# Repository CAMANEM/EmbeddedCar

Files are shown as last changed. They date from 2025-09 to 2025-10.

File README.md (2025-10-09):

# EmbeddedCar Project

This project contains the development environment for an embedded car system, organized in a clean and modular structure.

## Table of Contents

- [System Architecture](#system-architecture)
- [Key Features](#key-features)
- [API Documentation](#api-documentation)
- [Project Structure](#project-structure)
- [Prerequisites Installation](#prerequisites-installation)
    - [Yocto Prerequisites](#yocto-prerequisites)
    - [Web Development Prerequisites](#web-development-prerequisites)
- [Project Instructions](#project-instructions)
    - [Embedded Development (Yocto)](#embedded-development-yocto)
    - [Web Development](#web-development)
- [Setup Instructions for New Developers](#setup-instructions-for-new-developers)
    - [1. Prerequisites Installation](#1-prerequisites-installation)
    - [2. Configure Git with Your GitLab Credentials](#2-configure-git-with-your-gitlab-credentials)
    - [3. Authentication Setup](#3-authentication-setup)
    - [4. Clone and Setup Repository](#4-clone-and-setup-repository)
    - [5. Configure VS Code for GitLab](#5-configure-vs-code-for-gitlab)
    - [6. Development Workflow](#6-development-workflow)
    - [7. Important Configuration Notes](#7-important-configuration-notes)
    - [8. Troubleshooting](#8-troubleshooting)
- [Version Information](#version-information)
- [Contributing](#contributing)
- [License](#license)

##  System Architecture

### Overall Architecture Diagram

```
┌─────────────────────────────────────────────────────────────────┐
│                        EmbeddedCar System                       │
└─────────────────────────────────────────────────────────────────┘
                                  │
                    ┌─────────────┼─────────────┐
                    │             │             │
         ┌──────────▼──────────┐  │  ┌─────────▼─────────┐
         │   Web Interface     │  │  │  Embedded System  │
         │   (Frontend)        │  │  │  (Raspberry Pi)   │
         └─────────────────────┘  │  └───────────────────┘
                    │             │             │
    ┌───────────────┼─────────────┼─────────────┼──────────────┐
    │               │             │             │              │
┌───▼───┐    ┌──────▼──────┐   ┌──▼──┐   ┌─────▼─────┐   ┌────▼────┐
│Angular│    │   Node.js   │   │HTTP │   │  Yocto    │   │ Hardware│
│Client │    │   Backend   │   │API  │   │  Linux    │   │ Control │
└───────┘    └─────────────┘   └─────┘   └───────────┘   └─────────┘
```

### Component Architecture

####  **Frontend-Angular 20.2.1**
```
┌─────────────────────────────────────────────────────────────┐
│                    Angular Frontend                         │
├─────────────────────────────────────────────────────────────┤
│  ┌─────────────┐  ┌──────────────┐  ┌─────────────────────┐ │
│  │ Dashboard   │  │   Services   │  │     Components      │ │
│  │ Component   │  │              │  │                     │ │
│  │             │  │ ┌──────────┐ │  │ ┌─────────────────┐ │ │
│  │ • Manual    │  │ │Movement  │ │  │ │ • D-pad Control │ │ │
│  │   Control   │  │ │Service   │ │  │ │ • Speed Slider  │ │ │
│  │ • Sensors   │  │ └──────────┘ │  │ │ • Video Stream  │ │ │
│  │ • Cameras   │  │ ┌──────────┐ │  │ │ • Status Panel  │ │ │
│  │ • FPV       │  │ │Auth      │ │  │ └─────────────────┘ │ │
│  │ • Config    │  │ │Service   │ │  │                     │ │
│  └─────────────┘  │ └──────────┘ │  └─────────────────────┘ │
└─────────────────────────────────────────────────────────────┘
```

#### **Backend- Node.js**
```
┌─────────────────────────────────────────────────────────────┐
│                    Node.js Backend API                      │
├─────────────────────────────────────────────────────────────┤
│  ┌─────────────┐  ┌──────────────┐  ┌─────────────────────┐ │
│  │   Routes    │  │ Middleware   │  │    Controllers      │ │
│  │             │  │              │  │                     │ │
│  │ • /api/move │  │ • CORS       │  │ • Movement Control  │ │
│  │ • /api/stop │  │ • Auth       │  │ • Camera Streaming  │ │
│  │ • /api/     │  │ • Logging    │  │ • Sensor Reading    │ │
│  │   camera    │  │ • Error      │  │ • GPIO Management   │ │
│  │ • /api/     │  │   Handling   │  │                     │ │
│  │   sensors   │  │              │  │                     │ │
│  └─────────────┘  └──────────────┘  └─────────────────────┘ │
└─────────────────────────────────────────────────────────────┘
```

####  **Embedded- Yocto Linux + Hardware**
```
┌─────────────────────────────────────────────────────────────┐
│                 Raspberry Pi Hardware                       │
├─────────────────────────────────────────────────────────────┤
│  ┌─────────────┐  ┌──────────────┐  ┌─────────────────────┐ │
│  │Yocto Linux  │  │   Drivers    │  │      Hardware       │ │
│  │             │  │              │  │                     │ │
│  │ • Custom    │  │ • GPIO       │  │ • DC Motors         │ │
│  │   Build     │  │ • Camera     │  │ • Servo Motors      │ │
│  │ • Minimal   │  │ • (gstreamer)│  │ • Camera Module     │ │
│  │   Kernel    │  │              │  │ • Power Management  │ │
│  │ • Network   │  │              │  │                     │ │
│  │   Stack     │  │              │  │                     │ │
│  └─────────────┘  └──────────────┘  └─────────────────────┘ │
└─────────────────────────────────────────────────────────────┘
```
### Communication 

The system follows a structured communication pattern that ensures reliable, real-time control of the integrated vehicle:

#### **1. User Interaction **
The user interacts with the system using multiple input methods:
- **Web Interface**: Pressing buttons, adjusting sliders, or using touch controls
- **Keyboard Input**: Using the arrow keys and spacebar for direct control

#### **2. Frontend Processing**
The Angular frontend processes user input and manages the interface:
- **Event Handling**: Captures user interactions (clicks, keystrokes, touch events)
- **State Handling**: Maintains the current vehicle state, speed settings, and connection status
- **Input Validation**: Ensures commands are within valid ranges (speed 0-100%, valid directions)
- **User Feedback**: Updates visual indicators and status displays immediately

#### **3. HTTP Communication **
The frontend communicates with the backend using RESTful HTTP requests:
- **Request Format**: Converts user actions into structured JSON payloads
- **API Calls**: Sends POST/GET requests to specific endpoints (/api/move/forward, /api/stop, etc.)
- **Error Handling**: Handles network timeouts, connection failures, and invalid responses
- **Retry Logic**: Implements automatic retries for failed requests

#### **4. Backend API **
The Node.js backend processes incoming requests and manages communication with the hardware:
- **Request Parsing**: Validates and parses incoming JSON data
- **Authentication**: Verifies user permissions and session validity
- **Command Translation**: Converts high-level commands into hardware-specific instructions
- **Concurrent Management**: Securely handles multiple simultaneous requests

#### **5. Hardware Control Layer (GPIO)**
The backend interacts directly with the Raspberry Pi hardware:
- **GPIO Management**: Controls digital pins for motor direction and speed
- **PWM Control**: Generates pulse-width modulation signals for precise speed control
- **Sensor Reading**: Monitors hardware sensors for status information
- **Security Checks**: Implements hardware-level security mechanisms

#### **6. Physical Response Layer**
Hardware responds to control signals:
- **Motor Control**: DC motors respond to direction and speed commands
- **Servo Control**: Steering servos adjust to specific angles
- **Sensor Feedback**: Hardware sensors provide real-time status information
- **Power Management**: Monitors battery levels and power consumption

#### **7. Feedback Loop**
The system maintains real-time feedback through a continuous monitoring cycle:
- **Status Monitoring**: The hardware continuously reports the current status
- **API Response**: The backend sends JSON responses with the current status
- **Frontend Updates**: Angular updates the interface with real-time information
- **Visual Feedback**: The user sees immediate feedback through status indicators and video streaming

#### **Communication Protocols Used**
- **HTTP/HTTPS**: Primary communication protocol between the frontend and backend
- **WebSocket**: For real-time video streaming and continuous status updates
- **GPIO Protocol**: Direct hardware communication on the Raspberry Pi

##  Key Features

### **Complete Web Interface**
- **Manual Control**: Interactive D-pad for directional movement
- **Keyboard Control**: Arrow keys functional from any section
- **Speed Control**: Slider for velocity adjustment (0-100%)

###  **Video System**
- **Real-time Streaming**: GStreamer + MJPEG fallback
- **FPV View**: Game-like control with overlays
- **Screenshot Capture**: Automatic PNG image download
- **Flexible Configuration**: Configurable IP and port

### **Embedded System**
- **Yocto Linux**: Optimized custom build
- **Raspberry Pi**: Native hardware support
- **REST API**: Node.js backend for communication
- **GPIO Control**: Direct motor and sensor management

### **Monitoring**
- **Vehicle Status**: Real-time visual indicators
- **Network Connection**: Connectivity monitoring
- **Sensors**: Dedicated section for telemetry

## API Documentation

### Base URL
```
http://raspberry-pi-ip:3000/api
```

### Authentication Endpoints

#### POST `/auth/login`
**Description**: Authenticate user and obtain access token
```json
Request Body:
{
  "username": "admin",
  "password": "password"
}

Response:
{
  "status": "success",
  "token": "jwt-token-here",
  "user": {
    "username": "admin",
    "role": "admin"
  }
}
```

### Movement Control Endpoints

#### POST `/move/forward`
**Description**: Move vehicle forward
```json
Request Body:
{
  "speed": 75,
  "duration": 1000
}

Response:
{
  "status": "Moving forward.",
  "speed": 75,
  "direction": "forward"
}
```

#### POST `/move/backward`
**Description**: Move vehicle backward
```json
Request Body:
{
  "speed": 50,
  "duration": 1000
}

Response:
{
  "status": "Moving backward.",
  "speed": 50,
  "direction": "backward"
}
```

#### POST `/move/left`
**Description**: Turn vehicle left
```json
Request Body:
{
  "angle": 45,
  "speed": 60
}

Response:
{
  "status": "Turning left.",
  "angle": 45,
  "speed": 60
}
```

#### POST `/move/right`
**Description**: Turn vehicle right
```json
Request Body:
{
  "angle": 45,
  "speed": 60
}

Response:
{
  "status": "Turning right.",
  "angle": 45,
  "speed": 60
}
```

#### POST `/move/stop`
**Description**: Stop all vehicle movement
```json
Response:
{
  "status": "Stopped.",
  "timestamp": "2025-10-07T20:30:00Z"
}
```

### Camera Endpoints

#### GET `/camera/gstreamer-stream`
**Description**: Get GStreamer video stream
```
Query Parameters:
- ip: Raspberry Pi IP address
- port: Stream port (default: 8080)

Response: Binary video stream
Content-Type: multipart/x-mixed-replace
```

#### GET `/camera/mjpeg-stream`
**Description**: Get MJPEG video stream (fallback)
```
Query Parameters:
- ip: Raspberry Pi IP address  
- port: Stream port (default: 8080)

Response: Binary MJPEG stream
Content-Type: multipart/x-mixed-replace
```

### Sensor Endpoints

#### GET `/sensors/status`
**Description**: Get all sensor readings
```json
Response:
{
  "temperature": 25.6,
  "humidity": 60.2,
  "distance": 150.5,
  "battery": 85,
  "timestamp": "2025-10-07T20:30:00Z"
}
```

### Error Responses

All endpoints may return these error responses:
```json
400 Bad Request:
{
  "error": "Invalid parameters",
  "message": "Speed must be between 0 and 100"
}

401 Unauthorized:
{
  "error": "Authentication required",
  "message": "Please provide valid credentials"
}

500 Internal Server Error:
{
  "error": "Hardware communication failed",
  "message": "Unable to control motors"
}
```

## Project Structure

```
EmbeddedCar/
├── .gitignore          # Git ignore rules for both embedded and web development
├── README.md           # This file - project overview
└── Embedded/           # Yocto/Embedded system development
    ├── bitbake/        # BitBake build system
    ├── meta/           # Core OpenEmbedded metadata
    ├── meta-poky/      # Poky distribution metadata
    ├── meta-yocto-bsp/ # BSP layers for supported hardware
    ├── scripts/        # Build and utility scripts
    ├── oe-init-build-env # Environment setup script
    └── ...             # Other Yocto components
```

## Prerequisites Installation

### Yocto Prerequisites

Make sure you have the following packages installed on your system (example for Ubuntu/Debian):

```bash
sudo apt-get install gawk wget git diffstat unzip texinfo gcc-multilib
build-essential chrpath socat cpio python3 python3-pip python3-pexpect
xz-utils debianutils iputils-ping python3-git python3-jinja2 python3-subunit
zstd liblz4-tool file locales libacl1
```
Or you can use the `yocto_setup_and_test.sh` in the main directory to automatically the basic dependencies for this Yocto project.

Refer to the [official Yocto documentation](https://docs.yoctoproject.org/current/brief-yoctoprojectqs/index.html#packages) for more details and supported operating systems.

### Web Development Prerequisites

For the web part, ensure you have:

- [Node.js](https://nodejs.org/) (recommended version: 18.x or higher)
- [npm](https://www.npmjs.com/) (comes with Node.js)

To install on Ubuntu/Debian:

```bash
sudo apt-get update
sudo apt-get install nodejs npm
```

Then, inside your web frontend directory (e.g., `WebInterface/`):

```bash
cd WebInterface/
$ npm install
$ npm install angular
$ npm install multer
$ npm install http-proxy-middleware

```

This will install all necessary dependencies for web development.

## Project Instructions

### Embedded Development (Yocto)

To set up the embedded development environment:

1. Navigate to the embedded directory:
   ```bash
   cd Embedded/
   ```

2. Source the build environment:
   ```bash
   source oe-init-build-env
   ```

3. Build the image for Raspberry Pi 4:

`bitbake rpi4-embeddedcar-image`

You can see the full deteiled instructions in the [README.Instr.md](Embedded/README.Instr.md)

### Web Development

## Setup Instructions for New Developers

This repository is hosted on both GitLab and GitHub:
- **Primary repository**: GitLab (for development)
- **Mirror repository**: GitHub (automatically synced)

**Due to the mirroring it is to make sure to commit the changes in the GitLab repository**, so follow these steps to clone the repository and configure it properly for GitLab development:

### 1. Prerequisites Installation

#### Install Git
Ensure Git is installed on your system:
```bash
git --version
```
If not installed, install it:
- **Ubuntu/Debian**: `sudo apt install git`

#### Install Visual Studio Code
Download and install VS Code from [https://code.visualstudio.com/](https://code.visualstudio.com/) or from Ubuntu Software.

### 2. Configure Git with Your GitLab Credentials

Set your GitLab username and email globally:
```bash
git config --global user.name "Your Full Name"
git config --global user.email "your.email@example.com"
```

### 3. Authentication Setup

#### Option A: SSH Key (Recommended)

1. **Generate SSH key** (if you don't have one):
```bash
ssh-keygen -t ed25519 -C "your.email@example.com"
```
Press Enter to accept defaults (saves to `~/.ssh/id_ed25519`)

2. **Add SSH key to ssh-agent**:
```bash
eval "$(ssh-agent -s)"
ssh-add ~/.ssh/id_ed25519
```

3. **Copy public key**:
```bash
cat ~/.ssh/id_ed25519.pub
```

4. **Add to GitLab**:
   - Go to GitLab.com → Avatar → **Preferences**
   - Left sidebar: **SSH Keys**
   - Paste your public key and click **Add key**

5. **Test connection**:
```bash
ssh -T git@gitlab.com
```

#### Option B: Personal Access Token

1. **Generate token in GitLab**:
   - Go to GitLab.com → Avatar → **Preferences**
   - Left sidebar: **Access Tokens**
   - Click **Add new token**
   - Set scopes: `api`, `read_repository`, `write_repository`, `read_user`, Set GitLab as default remote:
```
git config remote.pushdefault gitlab
```
   - Copy the generated token

2. **Store credentials** (Git will prompt when needed):
```bash
git config --global credential.helper store
```

### 4. Clone and Setup Repository

1. **Clone the repository**:
```bash
# Using SSH (recommended if you set up SSH key)
git clone git@gitlab.com:camanem/EmbeddedCar.git

# OR using HTTPS (if using Personal Access Token)
git clone https://gitlab.com/camanem/EmbeddedCar.git
```

2. **Navigate to project directory**:
```bash
cd EmbeddedCar
```

3. **Set up remotes properly**:
```bash
# Verify current remotes
git remote -v

# Add GitLab as primary remote (if not already set)
git remote add gitlab git@gitlab.com:camanem/EmbeddedCar.git

# Set GitLab as default push remote
git config remote.pushdefault gitlab
git config push.default current
```

4. **Switch to development branch**:
```bash
git checkout development
```

### 5. Configure VS Code for GitLab

1. **Open project in VS Code**:
```bash
code .
```

2. **Install recommended extensions**:
   - **GitLab Workflow**: `GitLab.gitlab-workflow`
   - **Git Graph**: `mhutchie.git-graph`
   - **Git Lens**: `eamodio.gitlens`

3. **Configure GitLab Workflow extension**:
   - Press `Ctrl+Shift+P` → type "GitLab: Add Account"
   - Enter GitLab instance URL: `https://gitlab.com`
   - Use your Personal Access Token if prompted

4. **Verify Source Control setup**:
   - Open Source Control panel (`Ctrl+Shift+G`)
   - Check that remote shows as GitLab
   - Make a test change and commit to verify it goes to GitLab

### 6. Development Workflow

#### Creating and Working on Branches

1. **Always branch from development**:
```bash
git checkout development
git pull gitlab development
git checkout -b your_new_branch_name
```

2. **Make changes and commit**:
```bash
# Stage changes
git add .

# Commit with descriptive message
git commit -m "feat: add new feature description"

# Push to GitLab
git push gitlab your_new_branch_name
```

3. **Create Merge Request**:
   - Go to GitLab project page
   - Create Merge Request from your branch to `development`
   - Add description and assign reviewers

#### VS Code Source Control Usage

- **Stage files**: Click `+` next to files in Source Control panel
- **Commit**: Type message and press `Ctrl+Enter`
- **Push**: Click `...` → Push (or `Ctrl+Shift+P` → "Git: Push")
- **Pull**: Click `...` → Pull (or `Ctrl+Shift+P` → "Git: Pull")

### 7. Important Configuration Notes

- **Never push directly to `main` or `master`**
- **Always create branches from `development`**
- **Commits automatically sync from GitLab to GitHub** (mirroring is configured)
- **Use GitLab for all development work**, GitHub is read-only mirror

### 8. Troubleshooting

#### If commits go to GitHub instead of GitLab:
```bash
git remote set-url origin git@gitlab.com:camanem/EmbeddedCar.git
git config remote.pushdefault origin
```

#### If authentication fails:
```bash
# For SSH
ssh -T git@gitlab.com

# For HTTPS, clear and re-enter credentials
git config --global --unset credential.helper
git config --global credential.helper store
```

#### To verify remote configuration:
```bash
git remote -v
git config --list | grep remote
```

## Version Information

- **Yocto Version**: Scarthgap (5.0.10)
- **Build System**: BitBake
- **Architecture**: Multi-platform embedded systems

## Contributing

Please make sure to:
1. Test your changes in a clean build environment
2. Update documentation when adding new features
3. Follow the existing code structure and naming conventions

## License

This project inherits the licenses from the Yocto Project:
- MIT License (see `Embedded/LICENSE.MIT`)
- GPL v2.0 (see `Embedded/LICENSE.GPL-2.0-only`)

For more information about the embedded components, see the documentation in `Embedded/documentation/`.

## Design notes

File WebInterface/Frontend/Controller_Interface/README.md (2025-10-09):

# EmbeddedCar - Controller Interface 

This is the web application for remotely controlling an integrated autonomous vehicle. This interface offers real-time control, video streaming, and monitoring via a responsive web dashboard.





## Table of Contents

- [Features](#features)
- [Technologies Used](#technologies-used)
- [Prerequisites](#prerequisites)
- [Installation](#installation)
- [Configuration](#configuration)
- [Development](#development)
- [Building](#building)
- [Project Structure](#project-structure)
- [API Integration](#api-integration)
- [Troubleshooting](#troubleshooting)

## Features

### **Vehicle Control**
- **Interactive D-pad**: Touch-friendly directional control
- **Global Keyboard Control**: Arrow keys work from any section
- **Speed Control**: Adjustable velocity slider (0-100%)
- **Real-time Status**: Live vehicle state indicators

### **Video System**
- **Live Streaming**: GStreamer and MJPEG support
- **FPV Mode**: First-person view with gaming-like controls
- **Screenshot Capture**: Save video frames as PNG files
- **Configurable Streaming**: Adjustable IP and port settings

###  **User Interface**
- **Multi-section Layout**: Manual, Sensors, Cameras, FPV, Configuration
- **Real-time Feedback**: Instant visual response to commands

### **Authentication & Security**
- **Login Component**: Dedicated login form with username/password validation
- **Session Management**: JWT token storage and automatic renewal
- **Route Protection**: AuthGuard prevents unauthorized access to dashboard
- **Secure Logout**: Complete session cleanup and redirection
- **Input Validation**: Client-side and server-side parameter validation
- **Error Handling**: User-friendly authentication error messages

## Technologies Used

- **Framework**: Angular 20.2.1
- **Language**: TypeScript
- **Styling**: CSS3 with Flexbox/Grid
- **Forms**: Angular Reactive Forms
- **HTTP Client**: Angular HttpClient for API communication
- **Routing**: Angular Router for navigation
- **Build Tool**: Angular CLI
- **Package Manager**: npm

## Prerequisites

Before running this application, ensure you have:

- **Node.js**: Version 18.x or higher
- **npm**: Version 9.x or higher (comes with Node.js)
- **Angular CLI**: Version 20.x
- **Modern Web Browser**: Chrome, Firefox, Safari, or Edge

### Installation of Prerequisites

```bash
# Install Node.js (Ubuntu/Debian)
sudo apt update
sudo apt install nodejs npm

# Install Angular CLI globally
npm install -g @angular/cli

# Verify installations
node --version
npm --version
ng version
```

##  Installation

1. **Clone the repository** (if not already done):
```bash
git clone <repository-url>
cd EmbeddedCar/WebInterface/Frontend/Controller_Interface
```

2. **Install dependencies**:
```bash
npm install
```

3. **Verify installation**:
```bash
npm list --depth=0
```

## Configuration

### Environment Configuration

Create or modify environment files for different deployment scenarios:

**src/environments/environment.ts** (Development):
```typescript
export const environment = {
  production: false,
  apiUrl: 'http://localhost:3000/api',
  raspberryPiDefaultIp: '192.168.0.117',
  streamPort: 8080,
  enableLogging: true
};
```

**src/environments/environment.prod.ts** (Production):
```typescript
export const environment = {
  production: true,
  apiUrl: 'http://your-raspberry-pi-ip:3000/api',
  raspberryPiDefaultIp: 'your-raspberry-pi-ip',
  streamPort: 8080,
  enableLogging: false
};
```

### Backend Connection

Make sure your backend API is running and accessible:
- **Development**: Backend should be running on `http://localhost:3000`
- **Production**: Update the API URL to match your Raspberry Pi's IP address

##  Development

### Development server

To start a local development server, run:

```bash
ng serve
```

Once the server is running, open your browser and navigate to `http://localhost:4200/`. The application will automatically reload whenever you modify any of the source files.

### Hot Reload Development

The development server supports hot reload, meaning:
- Changes to TypeScript files trigger automatic recompilation
- CSS changes are applied instantly without page refresh
- Template changes update the DOM automatically
- The browser automatically refreshes when needed

### Development Tools

Recommended browser extensions for development:
- **Angular DevTools**: For debugging Angular applications
- **Redux DevTools**: If using state management
- **JSON Formatter**: For API response debugging

##  Project Structure

```
src/
├── app/
│   ├── login/                    
│   │   ├── login.ts              
│   │   ├── login.html            
│   │   └── login.css             
│   ├── dashboard/               
│   │   ├── dashboard.ts          
│   │   ├── dashboard.html        
│   │   └── dashboard.css         
│   ├── services/                 
│   │   ├── auth.service.ts       
│   │   └── movement.service.ts   
│   ├── guards/                   
│   │   └── auth.guard.ts         
│   ├── models/                   
│   │   ├── user.model.ts        
│   │   └── api-response.model.ts 
│   ├── app.routes.ts             
│   ├── app.component.ts         
│   ├── app.component.html        
│   └── app.component.css         
├── assets/                       
│   ├── images/                   
│   └── icons/                   
├── environments/                 
│   ├── environment.ts            
│   └── environment.prod.ts       
└── styles.css                   
```

### Key Components

#### **Components**
- **LoginComponent**: User authentication interface with form validation
- **DashboardComponent**: Main control interface with all vehicle control sections
- **AppComponent**: Root component handling routing and global layout

#### **Services**
- **AuthService**: Handles user authentication, session management, and token storage
- **MovementService**: Manages all vehicle control API calls and responses

#### **Guards & Security**
- **AuthGuard**: Protects routes requiring authentication
- **Route Protection**: Prevents unauthorized access to dashboard

#### **Models & Interfaces**
- **User Model**: TypeScript interface for user data structure
- **API Response Models**: Interfaces for backend response handling

##  API Integration

The frontend communicates with the backend through HTTP requests:

### Service Configuration

```typescript
// movement.service.ts example
@Injectable({
  providedIn: 'root'
})
export class MovementService {
  private apiUrl = environment.apiUrl;
  
  moveForward(speed: number): Observable<any> {
    return this.http.post(`${this.apiUrl}/move/forward`, { speed });
  }
}
```

### Error Handling

The application includes robust error handling:
- Network connectivity issues
- API server unavailability
- Invalid response formats
- Authentication failures

## Code scaffolding

Angular CLI includes powerful code scaffolding tools. To generate a new component, run:

```bash
ng generate component component-name
```

For a complete list of available schematics (such as `components`, `directives`, or `pipes`), run:

```bash
ng generate --help
```

## Building

To build the project run:

```bash
ng build
```

This will compile your project and store the build artifacts in the `dist/` directory. By default, the production build optimizes your application for performance and speed.

##  Troubleshooting

### Common Issues and Solutions

#### **Issue**: Application won't start
```bash
# Clear npm cache and reinstall
npm cache clean --force
rm -rf node_modules package-lock.json
npm install
```

#### **Issue**: Cannot connect to backend API
- Verify backend server is running on correct port
- Check CORS configuration in backend
- Confirm API URL in environment files
- Check API endpoints with browser developer tools

#### **Issue**: Video streaming not working
- Verify Raspberry Pi IP address and port
- Check network connectivity to Raspberry Pi
- Ensure GStreamer is properly configured on Pi
- Try MJPEG fallback option

#### **Issue**: Keyboard controls not responding
- Check browser console for JavaScript errors
- Verify event listeners are properly attached
- Ensure no other elements are capturing key events
- Try refreshing the browser or clearing cache

#### **Issue**: Build failures
```bash
# Update Angular CLI and dependencies
npm update -g @angular/cli
npm update
ng update
```

### Browser Compatibility
- Chrome 90+
- Firefox 88+
- Safari 14+
- Edge 90+

##  Additional Resources

### Angular Documentation
- [Angular Official Documentation](https://angular.dev)
- [Angular CLI Command Reference](https://angular.dev/tools/cli)
- [TypeScript Handbook](https://www.typescriptlang.org/docs/)

### Project-Specific Resources
- [Backend API Documentation](../../../Backend/README.md)
- [Embedded System Documentation](../../../Embedded/README.md)
- [Main Project README](../../../README.md)

### Development Tools
- [Angular DevTools](https://angular.dev/tools/devtools)
- [VS Code Angular Extensions](https://marketplace.visualstudio.com/items?itemName=Angular.ng-template)

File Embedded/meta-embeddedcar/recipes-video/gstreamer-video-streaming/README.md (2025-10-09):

# 🎥 GStreamer Video Streaming - Receta Yocto

## 📋 Descripción

Esta receta Yocto integra completamente el sistema de video streaming GStreamer en tu imagen de Raspberry Pi 4, proporcionando:

- ✅ **Servicio systemd** automático al arranque
- ✅ **Script de control** bash completo
- ✅ **Aplicación C++** de control avanzado
- ✅ **Configuración** centralizada
- ✅ **Logging** y monitoreo

## 📁 Estructura de la Receta

```
meta-embeddedcar/recipes-video/gstreamer-video-streaming/
├── gstreamer-video-streaming_1.0.0.bb     # Receta principal
└── files/
    ├── gstreamer-video-streaming           # Script bash principal
    ├── gstreamer-video.conf               # Archivo de configuración
    ├── gstreamer-video-streaming.service  # Servicio systemd
    ├── gstreamer_controller.cpp           # Controlador C++
    └── CMakeLists.txt                     # Build system
```

## 🚀 Instalación en Yocto

### 1. **La receta ya está incluida en tu imagen:**

```bitbake
# En: meta-embeddedcar/recipes-core/images/rpi4-embeddedcar-image.bb
IMAGE_INSTALL += "gstreamer-video-streaming"
```

### 2. **Construir la imagen:**

```bash
cd /home/camanem/EmbeddedCar/Embedded
source oe-init-build-env rpi4
bitbake rpi4-embeddedcar-image
```

### 3. **La imagen incluirá automáticamente:**

- `/usr/bin/gstreamer-video-streaming` - Script principal
- `/usr/bin/gstreamer_controller` - Controlador C++
- `/etc/gstreamer-video.conf` - Configuración
- `/lib/systemd/system/gstreamer-video-streaming.service` - Servicio
- Todas las dependencias GStreamer necesarias

## 🔧 Uso en Raspberry Pi

### **Servicio SystemD (Automático)**

```bash
# El servicio inicia automáticamente al arrancar
systemctl status gstreamer-video-streaming

# Control manual
systemctl start gstreamer-video-streaming
systemctl stop gstreamer-video-streaming
systemctl restart gstreamer-video-streaming

# Ver logs
journalctl -u gstreamer-video-streaming -f
```

### **Script Bash**

```bash
# Control directo
gstreamer-video-streaming start
gstreamer-video-streaming stop
gstreamer-video-streaming status
gstreamer-video-streaming config

# Con variables de entorno
VIDEO_PORT=8090 gstreamer-video-streaming start
VIDEO_WIDTH=1280 VIDEO_HEIGHT=720 gstreamer-video-streaming start
```

### **Controlador C++**

```bash
# Control desde aplicación C++
gstreamer_controller start
gstreamer_controller stop
gstreamer_controller status

# Con parámetros
gstreamer_controller start --port=8090 --quality=95
gstreamer_controller start --width=1280 --height=720
```

## ⚙️ Configuración

### **Archivo: `/etc/gstreamer-video.conf`**

```bash
# Video Device
VIDEO_DEVICE="/dev/video0"

# Resolution  
VIDEO_WIDTH="640"
VIDEO_HEIGHT="480"
VIDEO_FRAMERATE="30"

# Network
VIDEO_HOST="0.0.0.0"
VIDEO_PORT="8080"

# Quality
VIDEO_QUALITY="85"

# Auto-start
AUTO_START="true"
```

### **Variables de Entorno Soportadas:**

- `VIDEO_DEVICE` - Dispositivo de video
- `VIDEO_WIDTH` / `VIDEO_HEIGHT` - Resolución
- `VIDEO_FRAMERATE` - FPS
- `VIDEO_PORT` - Puerto TCP
- `VIDEO_QUALITY` - Calidad JPEG (1-100)
- `VIDEO_HOST` - Host bind

## 📊 Dependencias Incluidas

### **Runtime (RDEPENDS):**

- `gstreamer1.0` - Core GStreamer
- `gstreamer1.0-plugins-base` - Plugins básicos
- `gstreamer1.0-plugins-good` - Plugins estables
- `gstreamer1.0-plugins-bad` - Plugins experimentales
- `v4l-utils` - Video4Linux utils
- `systemd` - Service management
- `bash` - Script execution

### **Recomendadas (RRECOMMENDS):**

- `gstreamer1.0-plugins-ugly` - Plugins adicionales
- `gstreamer1.0-libav` - Codecs FFmpeg
- `gstreamer1.0-omx` - Hardware acceleration
- `kernel-module-uvcvideo` - USB camera support

## 🔍 Debugging y Logs

### **Logs del Sistema:**

```bash
# SystemD logs
journalctl -u gstreamer-video-streaming -f

# Archivo de log directo
tail -f /var/log/gstreamer-video.log

# Estado del servicio
systemctl status gstreamer-video-streaming
```

### **Verificación Manual:**

```bash
# Verificar dispositivo de video
ls -la /dev/video*

# Verificar puerto
netstat -tlpn | grep :8080

# Test GStreamer manual
gst-launch-1.0 v4l2src device=/dev/video0 ! fakesink
```

## 🌐 Integración Web

### **Tu servidor Node.js puede consumir el stream:**

```javascript
// Endpoint ya implementado:
GET /api/camera/gstreamer-stream?ip=192.168.0.106&port=8080
```

### **Interfaz web disponible:**

```
http://localhost:3000/gstreamer_video.html
```

## 🎯 Ventajas de esta Implementación

### ✅ **Integración Completa**
- Automáticamente incluido en imagen Yocto
- Servicio systemd nativo
- Configuración centralizada

### ✅ **Producción Ready**
- Auto-start en arranque
- Logging completo
- Monitoreo systemd
- Configuración segura

### ✅ **Flexible**
- Control via systemd, bash script, o C++
- Configuración por archivo o variables
- Parámetros runtime ajustables

### ✅ **Mantenible**
- Código fuente en receta
- Versionado con imagen
- Dependencias gestionadas automáticamente

## 🔄 Proceso de Build

```bash
# 1. La receta se procesa durante bitbake
bitbake gstreamer-video-streaming

# 2. Se incluye automáticamente en la imagen
bitbake rpi4-embeddedcar-image

# 3. Al flashear e iniciar RPi4:
#    - Servicio se instala
#    - Se habilita automáticamente  
#    - Inicia en boot
#    - Stream disponible en puerto 8080
```

## ✨ **¡Completamente Automatizado!**

Con esta receta, tu Raspberry Pi 4:

1. **🚀 Arranca** con video streaming automático
2. **📡 Expone** TCP stream en puerto 8080  
3. **🔧 Permite** control completo via systemd/scripts
4. **📋 Registra** todo en logs sistemd
5. **🌐 Integra** perfectamente con tu API Node.js

**¡Tu solución de video streaming está lista para producción!** 🎬

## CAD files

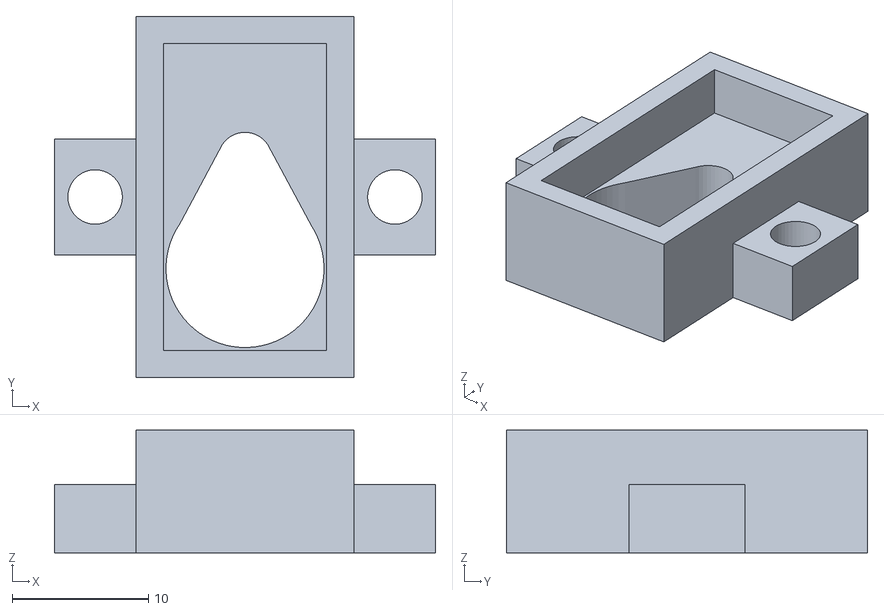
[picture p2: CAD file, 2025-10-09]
3dModels/servoHolder.stl
28.0 x 26.5 x 9.00

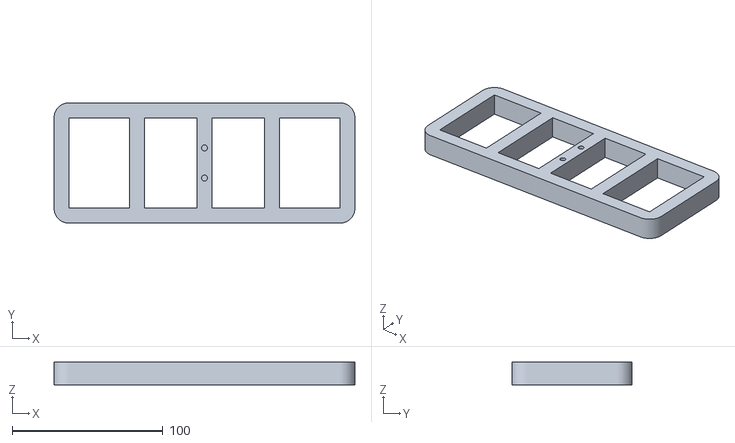
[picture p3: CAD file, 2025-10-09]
3dModels/chassis.stl
200.0 x 80.0 x 15.0

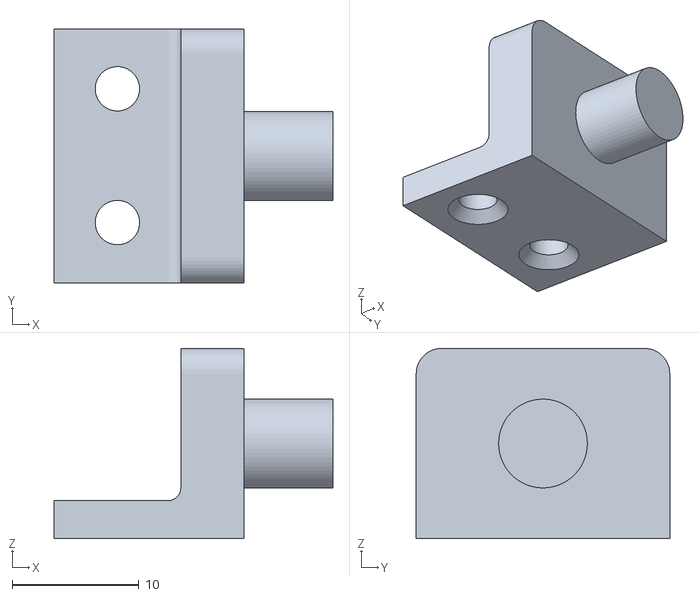
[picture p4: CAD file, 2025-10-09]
3dModels/wheelAdapter.stl
22.0 x 20.0 x 15.0

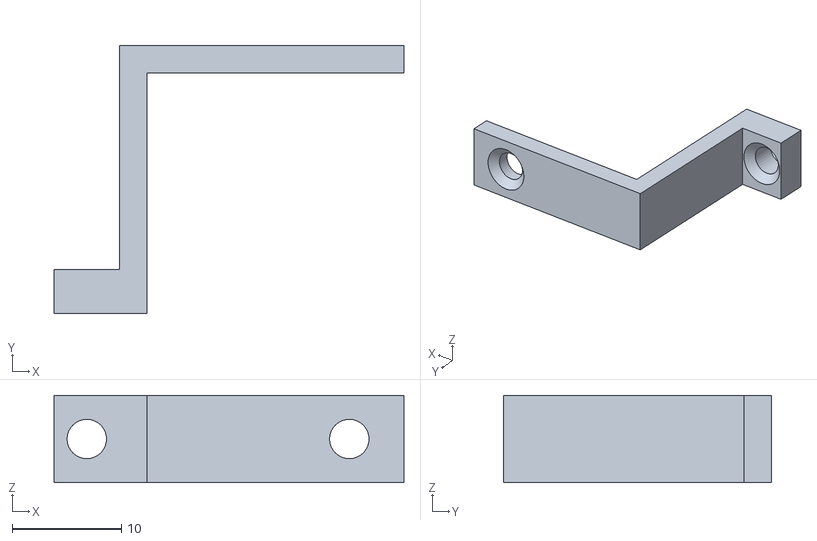
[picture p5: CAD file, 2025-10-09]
3dModels/servoHolderArm.stl
32.0 x 24.5 x 8.00

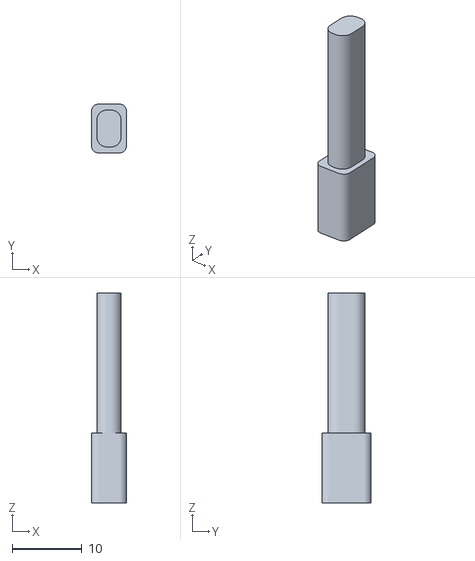
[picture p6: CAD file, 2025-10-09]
3dModels/motorToWheel.stl
5.00 x 7.00 x 30.0

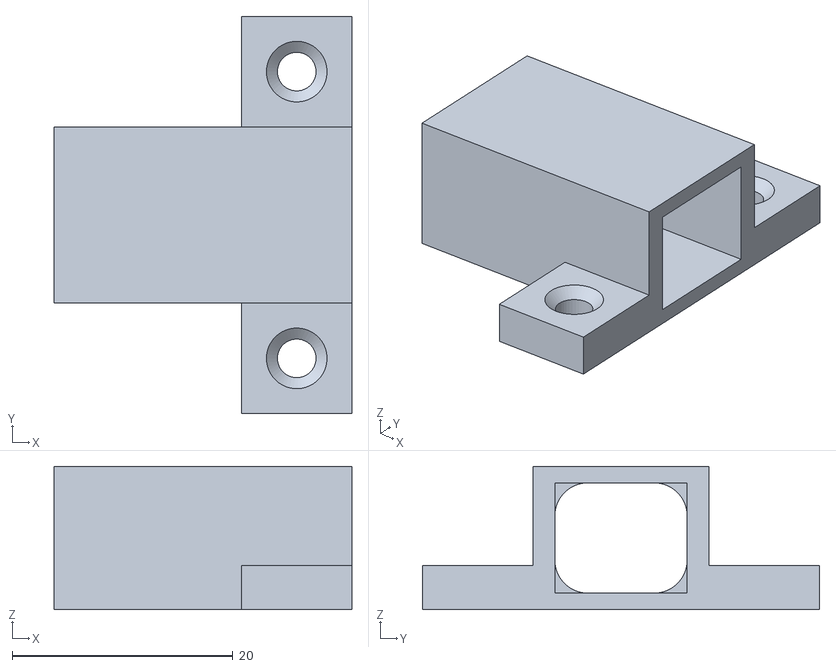
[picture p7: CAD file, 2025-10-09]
3dModels/motorBracketSmall.stl
27.0 x 36.0 x 13.0

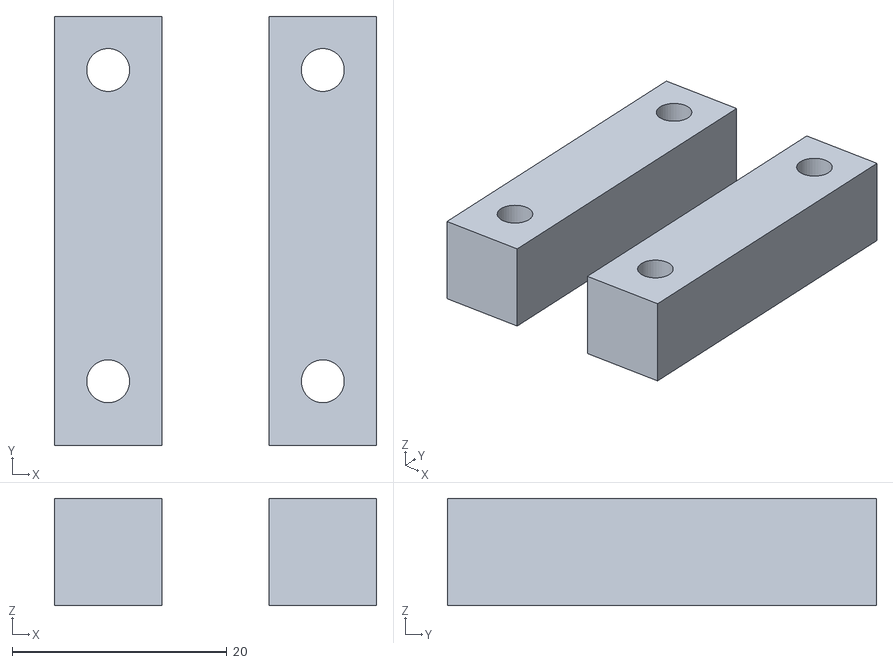
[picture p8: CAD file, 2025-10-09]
3dModels/motorSpacers.stl
30.0 x 40.0 x 10.0

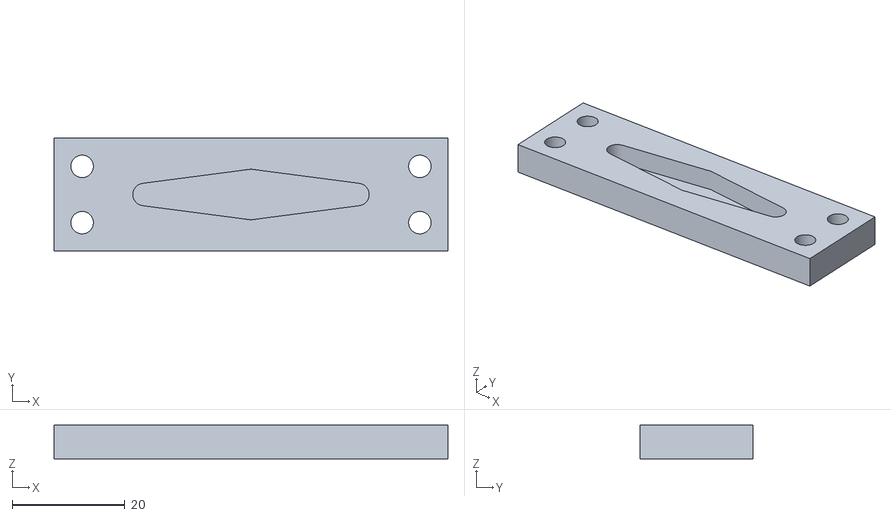
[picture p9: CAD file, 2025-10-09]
3dModels/Direction.stl
70.0 x 20.0 x 6.00

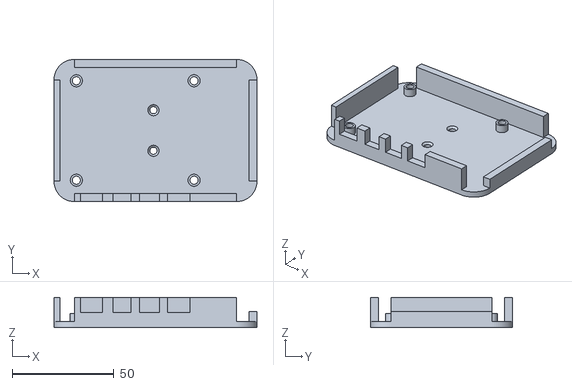
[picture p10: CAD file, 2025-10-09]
3dModels/rpi4Case.stl
100.0 x 70.0 x 15.0

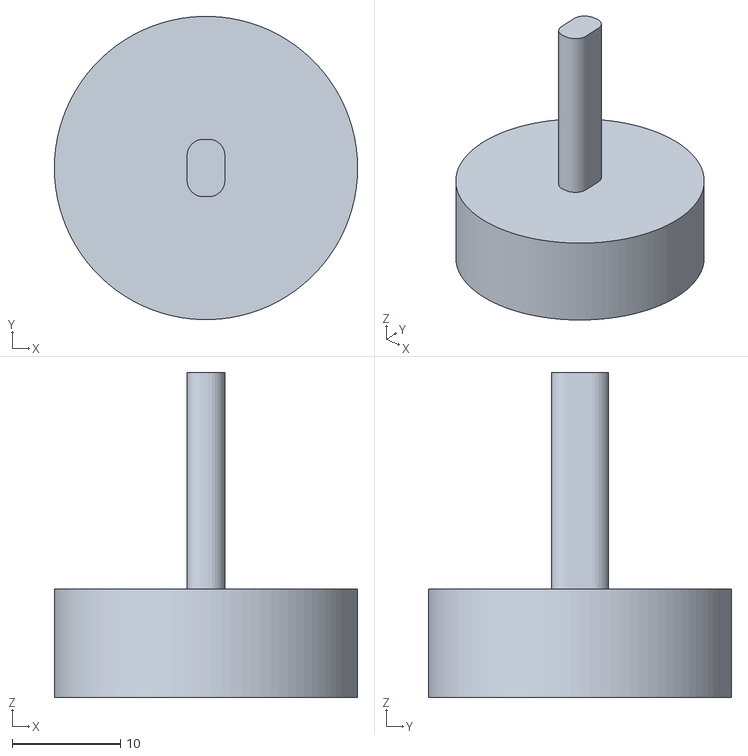
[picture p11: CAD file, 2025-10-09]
3dModels/rollAdapter.stl
28.0 x 28.0 x 30.0

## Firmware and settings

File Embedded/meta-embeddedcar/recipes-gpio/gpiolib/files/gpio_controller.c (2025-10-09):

#include "gpio_lib.h"
#include <json-c/json.h>
#include <signal.h>
#include <sys/time.h>
#include <sys/wait.h>

// GPIO Pin definitions for car control
#define LED_FORWARD_RIGHT 17
#define LED_FORWARD_LEFT 27
#define LED_BACKWARD_LEFT 6
#define LED_BACKWARD_RIGHT 5
#define PWM_MOTOR_LEFT_1 22
#define PWM_MOTOR_LEFT_2 23
#define PWM_MOTOR_RIGHT_1 26
#define PWM_MOTOR_RIGHT_2 16
#define PWM_SERVO 12


// Car control structure
typedef struct {
    char movement[16];
    int speed;
    char direction[16];
} CarCommand;

// Global variables
volatile int running = 1;
CarCommand last_command = {"stop", 0, "center"};
char server_ip[16] = "10.90.36.240";  // IP por defecto, puede ser modificada por argumento

// Signal handler for clean shutdown
void signal_handler(int sig) {
    //printf("\n Received signal %d, shutting down gracefully...\n", sig);
    running = 0;
}

// Validar formato básico de IP
int is_valid_ip_format(const char *ip) {
    int dots = 0;
    int digit_count = 0;
    
    for (int i = 0; ip[i] != '\0'; i++) {
        if (ip[i] == '.') {
            if (digit_count == 0 || digit_count > 3) return 0; // No digits before dot or too many
            dots++;
            digit_count = 0;
        } else if (ip[i] >= '0' && ip[i] <= '9') {
            digit_count++;
        } else {
            return 0; // Invalid character
        }
    }
    
    // Should have exactly 3 dots and end with digits
    return (dots == 3 && digit_count > 0 && digit_count <= 3);
}

// Parse JSON response and extract car command
int parse_car_command(const char *json_string, CarCommand *cmd) {
    json_object *root, *movement_obj, *speed_obj, *direction_obj;
    
    root = json_tokener_parse(json_string);
    if (root == NULL) {
        printf("❌ Failed to parse JSON\n");
        return -1;
    }
    
    // Extract movement
    if (json_object_object_get_ex(root, "movement", &movement_obj)) {
        const char *movement = json_object_get_string(movement_obj);
        strncpy(cmd->movement, movement, sizeof(cmd->movement) - 1);
        cmd->movement[sizeof(cmd->movement) - 1] = '\0';
    } else {
        strcpy(cmd->movement, "stop");
    }
    
    // Extract speed
    if (json_object_object_get_ex(root, "speed", &speed_obj)) {
        cmd->speed = json_object_get_int(speed_obj);
    } else {
        cmd->speed = 0;
    }
    
    // Extract direction
    if (json_object_object_get_ex(root, "direction", &direction_obj)) {
        const char *direction = json_object_get_string(direction_obj);
        strncpy(cmd->direction, direction, sizeof(cmd->direction) - 1);
        cmd->direction[sizeof(cmd->direction) - 1] = '\0';
    } else {
        strcpy(cmd->direction, "center");
    }
    
    json_object_put(root);
    return 0;
}

// Make HTTP request using wget and get car command
int fetch_car_command(CarCommand *cmd) {
    FILE *fp;
    char buffer[1024];
    char wget_command[256];
    int result = -1;
    
    // Build wget command with timeout and quiet mode
    snprintf(wget_command, sizeof(wget_command), 
             "wget -q --timeout=2 --tries=1 \"http://%s:3000/api/car/movement\" -O -", server_ip);
    
    // Execute wget command and read output
    fp = popen(wget_command, "r");
    if (fp == NULL) {
        printf("❌ Failed to execute wget command\n");
        return -1;
    }
    
    // Read the JSON response
    if (fgets(buffer, sizeof(buffer), fp) != NULL) {
        // Remove newline if present
        buffer[strcspn(buffer, "\n")] = 0;
        
        //printf("Received: %s\n", buffer);
        result = parse_car_command(buffer, cmd);
    } else {
        printf("❌ No data received from API\n");
    }
    
    // Close pipe and check exit status
    int status = pclose(fp);
    if (status != 0) {
        printf("❌ wget failed with status %d\n", status);
        return -1;
    }
    
    return result;
}

// Initialize all GPIO pins
void init_gpio_pins() {
    
    // control pins
    pinMode(LED_FORWARD_LEFT, OUTPUT);
    pinMode(LED_FORWARD_RIGHT, OUTPUT);
    pinMode(LED_BACKWARD_LEFT, OUTPUT);
    pinMode(LED_BACKWARD_RIGHT, OUTPUT);
    pinMode(PWM_MOTOR_LEFT_1, OUTPUT);
    pinMode(PWM_MOTOR_LEFT_2, OUTPUT);
    pinMode(PWM_MOTOR_RIGHT_1, OUTPUT);
    pinMode(PWM_MOTOR_RIGHT_2, OUTPUT);
    
    // Initialize servo (hardware PWM)
    servoInit(PWM_SERVO);
    
    // Initialize all LEDS to OFF
    digitalWrite(LED_FORWARD_LEFT, LOW);
    digitalWrite(LED_FORWARD_RIGHT, LOW);
    digitalWrite(LED_BACKWARD_LEFT, LOW);
    digitalWrite(LED_BACKWARD_RIGHT, LOW);
    
    // Initialize all MOTORS to OFF
    softPwmStart(PWM_MOTOR_LEFT_1, 0, 500);
    softPwmStart(PWM_MOTOR_LEFT_2, 0, 500);
    softPwmStart(PWM_MOTOR_RIGHT_1, 0, 500);
    softPwmStart(PWM_MOTOR_RIGHT_2, 0, 500);

    
}



// Función para cambiar frecuencia PWM de motores (para testing)
void set_motor_frequency(int freq) {
    
    // Detener PWM actuales
    softPwmStop(PWM_MOTOR_LEFT_1);
    softPwmStop(PWM_MOTOR_LEFT_2);
    softPwmStop(PWM_MOTOR_RIGHT_1);
    softPwmStop(PWM_MOTOR_RIGHT_2);
    
    // Reiniciar con nueva frecuencia
    softPwmStart(PWM_MOTOR_LEFT_1, 0, freq);
    softPwmStart(PWM_MOTOR_LEFT_2, 0, freq);
    softPwmStart(PWM_MOTOR_RIGHT_1, 0, freq);
    softPwmStart(PWM_MOTOR_RIGHT_2, 0, freq);
    
    //printf("Frecuencia de motores actualizada a %dHz\n", freq);
}

// Stop all motors
void stop_all() {
    // Detener todos los LEDs de parpadeo
    blinkStop(LED_FORWARD_LEFT);
    blinkStop(LED_FORWARD_RIGHT);
    blinkStop(LED_BACKWARD_LEFT);
    blinkStop(LED_BACKWARD_RIGHT);
    
    // Apagar todos los LEDs
    digitalWrite(LED_FORWARD_LEFT, LOW);
    digitalWrite(LED_FORWARD_RIGHT, LOW);
    digitalWrite(LED_BACKWARD_LEFT, LOW);
    digitalWrite(LED_BACKWARD_RIGHT, LOW);

    // Detener todos los motores
    softPwmUpdateDuty(PWM_MOTOR_LEFT_1, 0);
    softPwmUpdateDuty(PWM_MOTOR_LEFT_2, 0);
    softPwmUpdateDuty(PWM_MOTOR_RIGHT_1, 0);
    softPwmUpdateDuty(PWM_MOTOR_RIGHT_2, 0);
}

// Control servo dirección con ángulos específicos (65° a 115°) usando PWM HARDWARE
void set_steering_direction(const char* direction) {
    if (strcmp(direction, "left") == 0) {
        // Girar a la izquierda (65°)
        servoWriteLimited(PWM_SERVO, 65, 65, 115);
    } else if (strcmp(direction, "right") == 0) {
        // Girar a la derecha (115°)
        servoWriteLimited(PWM_SERVO, 115, 65, 115);
    } else {
        // Centro (90°)
        servoWriteLimited(PWM_SERVO, 90, 65, 115);
    }
}

// Execute car movement based on command
void execute_car_command(const CarCommand *cmd) {
    //printf("Executing: movement=%s, speed=%d, direction=%s\n", 
    //       cmd->movement, cmd->speed, cmd->direction);
    
    //stop_all();

    set_steering_direction(cmd->direction);

    // Basic movement control
    if (strcmp(cmd->movement, "forward") == 0) {
        if (strcmp(cmd->direction, "left") == 0) {
            // Forward + Left: Reduce left motor speed or reverse it slightly
            blinkStart(LED_FORWARD_LEFT, 2, 3); // Blink left LED to indicate turn
            blinkStart(LED_BACKWARD_LEFT, 2, 3); // Blink left LED to indicate turn
            
            softPwmUpdateDuty(PWM_MOTOR_LEFT_1, 0);
            softPwmUpdateDuty(PWM_MOTOR_LEFT_2, cmd->speed);
            softPwmUpdateDuty(PWM_MOTOR_RIGHT_1, cmd->speed);
            softPwmUpdateDuty(PWM_MOTOR_RIGHT_2, 0);
            
            
            } else if (strcmp(cmd->direction, "right") == 0) {
            // Forward + Right: Reduce right motor speed or reverse it slightly
            blinkStart(LED_FORWARD_RIGHT, 2, 3); // Blink right LED to indicate turn
            blinkStart(LED_BACKWARD_RIGHT, 2, 3); // Blink right LED to indicate turn

            softPwmUpdateDuty(PWM_MOTOR_LEFT_1, cmd->speed);
            softPwmUpdateDuty(PWM_MOTOR_LEFT_2, 0);
            softPwmUpdateDuty(PWM_MOTOR_RIGHT_1, 0);
            softPwmUpdateDuty(PWM_MOTOR_RIGHT_2, cmd->speed);
        } else {
            // Forward straight
            digitalWrite(LED_FORWARD_LEFT, HIGH);
            digitalWrite(LED_FORWARD_RIGHT, HIGH);

            softPwmUpdateDuty(PWM_MOTOR_LEFT_1, cmd->speed);
            softPwmUpdateDuty(PWM_MOTOR_LEFT_2, 0);
            softPwmUpdateDuty(PWM_MOTOR_RIGHT_1, cmd->speed);
            softPwmUpdateDuty(PWM_MOTOR_RIGHT_2, 0);
        }
    } else if (strcmp(cmd->movement, "backward") == 0) {
        if (strcmp(cmd->direction, "left") == 0) {
            // Backward + Left
            blinkStart(LED_BACKWARD_LEFT, 2, 3); // Blink left LED to indicate turn
            blinkStart(LED_FORWARD_LEFT, 2, 3); // Blink left LED to indicate turn

            softPwmUpdateDuty(PWM_MOTOR_LEFT_1, cmd->speed);
            softPwmUpdateDuty(PWM_MOTOR_LEFT_2, 0);
            softPwmUpdateDuty(PWM_MOTOR_RIGHT_1, 0);
            softPwmUpdateDuty(PWM_MOTOR_RIGHT_2, cmd->speed);

        } else if (strcmp(cmd->direction, "right") == 0) {
            // Backward + Right
            blinkStart(LED_BACKWARD_RIGHT, 2, 3); // Blink right LED to indicate turn
            blinkStart(LED_FORWARD_RIGHT, 2, 3); // Blink right LED to indicate turn

            softPwmUpdateDuty(PWM_MOTOR_LEFT_1, 0);
            softPwmUpdateDuty(PWM_MOTOR_LEFT_2, cmd->speed);
            softPwmUpdateDuty(PWM_MOTOR_RIGHT_1, cmd->speed);
            softPwmUpdateDuty(PWM_MOTOR_RIGHT_2, 0);

        } else {
            // Backward straight
            digitalWrite(LED_BACKWARD_LEFT, HIGH);
            digitalWrite(LED_BACKWARD_RIGHT, HIGH);

            softPwmUpdateDuty(PWM_MOTOR_LEFT_1, 0);
            softPwmUpdateDuty(PWM_MOTOR_LEFT_2, cmd->speed);
            softPwmUpdateDuty(PWM_MOTOR_RIGHT_1, 0);
            softPwmUpdateDuty(PWM_MOTOR_RIGHT_2, cmd->speed);
        }
    } else if (strcmp(cmd->movement, "left") == 0) {
        // Turn left in place
        blinkStart(LED_FORWARD_LEFT, 2, 3);
        blinkStart(LED_BACKWARD_LEFT, 2, 3);
    } else if (strcmp(cmd->movement, "right") == 0) {
        // Turn right in place
        blinkStart(LED_FORWARD_RIGHT, 2, 3);
        blinkStart(LED_BACKWARD_RIGHT, 2, 3);
    } else {
        // Stop or unknown command
        stop_all();
    }
}

// Timer callback function (called every 250ms)
void timer_callback(int sig) {
    CarCommand new_command;
    
    // Fetch new command from API
    if (fetch_car_command(&new_command) == 0) {
        // Only execute if command changed
        if (strcmp(last_command.movement, new_command.movement) != 0 ||
            last_command.speed != new_command.speed ||
            strcmp(last_command.direction, new_command.direction) != 0) {
            
            execute_car_command(&new_command);
            last_command = new_command;
        }
    } else {
        // If HTTP request fails, stop the car for safety
        printf("HTTP request failed, stopping car for safety\n");
        CarCommand stop_cmd = {"stop", 0, "center"};
        execute_car_command(&stop_cmd);
        last_command = stop_cmd;
    }
}

// Setup timer for periodic HTTP requests
void setup_timer() {
    struct sigaction sa;
    struct itimerval timer;
    
    // Install timer signal handler
    memset(&sa, 0, sizeof(sa));
    sa.sa_handler = &timer_callback;
    sigaction(SIGALRM, &sa, NULL);
    
    // Configure timer for 250ms interval
    timer.it_value.tv_sec = 0;
    timer.it_value.tv_usec = 250000;  // 250ms
    timer.it_interval.tv_sec = 0;
    timer.it_interval.tv_usec = 250000;  // 250ms
    
    // Start timer
    setitimer(ITIMER_REAL, &timer, NULL);
}

int main(int argc, char *argv[]) {

    // Procesar argumentos de línea de comandos (ip default o dada por parámetro)
    if (argc > 1) {
        // Validar formato de IP básico
        if (strlen(argv[1]) < sizeof(server_ip) && is_valid_ip_format(argv[1])) {
            strncpy(server_ip, argv[1], sizeof(server_ip) - 1);
            server_ip[sizeof(server_ip) - 1] = '\0';
            //printf("Usando IP del servidor: %s\n", server_ip);
        } else {
            //printf("❌ Error: Formato de IP inválido '%s'. Usando IP por defecto: %s\n", argv[1], server_ip);
            //printf("Formato esperado: xxx.xxx.xxx.xxx (ejemplo: 192.168.1.100)\n");
        }
    } else {
        //printf("Usando IP por defecto: %s\n", server_ip);
        //printf("Uso: %s [IP_SERVIDOR] (ejemplo: %s 192.168.1.100)\n", argv[0], argv[0]);
    }
    
    // Install signal handlers for clean shutdown
    signal(SIGINT, signal_handler);
    signal(SIGTERM, signal_handler);
    
    // Initialize GPIO
    init_gpio_pins();

    // Setup periodic timer
    setup_timer();
    
  
    // Main loop - just wait for signals
    while (running) {
        sleep(1);
    }
    
    // Cleanup
    //printf("\n🧹 Cleaning up...\n");
    stop_all();
    
    // Detener servo HARDWARE PWM y centrarlo
    set_steering_direction("center");
    usleep(500000); // Esperar 500ms para que alcance la posición
    servoStop(PWM_SERVO);
    
    return 0;
}

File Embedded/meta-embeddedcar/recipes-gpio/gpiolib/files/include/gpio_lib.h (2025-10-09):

#ifndef GPIO_LIB_H
#define GPIO_LIB_H

#define _GNU_SOURCE

#include <stdio.h>
#include <stdlib.h>
#include <string.h>
#include <unistd.h>



// Pin modes
typedef enum {
    OUTPUT = 0,  /**< Modo salida digital */
    INPUT = 1,   /**< Modo entrada digital */
    PWM = 2,     /**< Modo PWM hardware */
    SOFT_PWM = 3 /**< Modo PWM software */
} Mode_t;

// Logic levels
typedef enum {
    LOW = 0,     /**< Nivel lógico bajo (0V) */
    HIGH = 1     /**< Nivel lógico alto (3.3V) */
} state_t;

/**
 * @brief Configura el modo de un pin GPIO
 * @param pin Número del pin GPIO (0-21)
 * @param mode Modo del pin (OUTPUT, INPUT, PWM)
 * @return 0 si es exitoso, código de error del sistema en caso contrario
 * 
 * @example
 * // Configurar pin 18 como salida digital
 * pinMode(18, OUTPUT);
 * 
 * // Configurar pin 12 como PWM
 * pinMode(12, PWM);
 * 
 * // Configurar pin 21 como entrada
 * pinMode(21, INPUT);
 */
int pinMode(int pin, Mode_t mode);

/**
 * @brief Escribe un valor digital en un pin configurado como OUTPUT
 * @param pin Número del pin GPIO
 * @param value Valor a escribir (HIGH o LOW)
 * @return 0 si es exitoso, código de error del sistema en caso contrario
 * 
 * @example
 * // Encender LED en pin 18
 * pinMode(18, OUTPUT);
 * digitalWrite(18, HIGH);
 * 
 * // Apagar LED
 * digitalWrite(18, LOW);
 */
int digitalWrite(int pin, state_t value);

/**
 * @brief Lee el valor digital de un pin configurado como INPUT
 * @param pin Número del pin GPIO
 * @return 1 si el pin está en HIGH, 0 si está en LOW, -1 en caso de error
 * 
 * @example
 * // Leer estado de un botón en pin 21
 * pinMode(21, INPUT);
 * int button_state = digitalRead(21);
 * if (button_state == HIGH) {
 *     printf("Botón presionado\n");
 * }
 */
int digitalRead(int pin);

/**
 * @brief Hace parpadear un LED con frecuencia y duración específicas (BLOQUEANTE)
 * @param pin Número del pin GPIO donde está conectado el LED
 * @param freq Frecuencia en Hz (parpadeos por segundo)
 * @param duration Duración total en segundos
 * 
 * @note Esta función es BLOQUEANTE - el programa se detiene hasta que termine
 * @note Para uso no bloqueante, usar blinkStart() y blinkStop()
 * 
 * @example
 * // Parpadear LED en pin 18 a 2Hz durante 5 segundos (BLOQUEANTE)
 * pinMode(18, OUTPUT);
 * blink(18, 2, 5);  // El programa se pausa aquí por 5 segundos
 * 
 * // Parpadeo rápido: 10Hz durante 2 segundos
 * blink(18, 10, 2); // 20 parpadeos total
 */
void blink(int pin, int freq, int duration);

/**
 * @brief Inicia parpadeo no bloqueante en background
 * @param pin Número del pin GPIO donde está conectado el LED
 * @param freq Frecuencia en Hz (parpadeos por segundo)
 * @param duration Duración total en segundos
 * @return 0 si es exitoso, código de error en caso contrario
 * 
 * @note Esta función es NO BLOQUEANTE - el programa continúa inmediatamente
 * @note El parpadeo se ejecuta en un thread separado
 * 
 * @example
 * // Parpadear LED mientras se ejecuta otro código
 * pinMode(17, OUTPUT);
 * blinkStart(17, 3, 10);  // Parpadear 3Hz por 10 segundos
 * 
 * // Continuar con otro código inmediatamente
 * printf("El LED está parpadeando en background\n");
 * 
 * // Opcional: detener antes de que termine
 * sleep(5);
 * blinkStop(17);  // Detener después de 5 segundos
 */
int blinkStart(int pin, int freq, int duration);

/**
 * @brief Detiene el parpadeo no bloqueante en un pin
 * @param pin Número del pin GPIO
 * @return 0 si es exitoso, -1 si no hay parpadeo activo en el pin
 * 
 * @example
 * // Parpadeo con control manual
 * blinkStart(18, 5, 60);  // Parpadear por 1 minuto
 * sleep(10);              // Esperar 10 segundos
 * blinkStop(18);          // Detener anticipadamente
 */
int blinkStop(int pin);

/**
 * @brief Escribe un valor PWM (duty cycle) en un pin configurado como PWM
 * @param pin Número del pin PWM (12, 13, 18, 19)
 * @param duty_cycle Ciclo de trabajo (0-1024, donde 1024 = 100%)
 * @return 0 si es exitoso, código de error del sistema en caso contrario
 * 
 * @example
 * // Control de servo en pin 12
 * pinMode(12, PWM);
 * pwmSetFrequency(12, 50);  // 50Hz para servos
 * pwmWrite(12, 77);         // ~1.5ms pulse (posición central)
 * 
 * // Control de velocidad de motor en pin 18
 * pinMode(18, PWM);
 * pwmWrite(18, 512);        // 50% velocidad
 * pwmWrite(18, 1024);       // 100% velocidad
 * pwmWrite(18, 0);          // Motor detenido
 */
int pwmWrite(int pin, int duty_cycle);
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

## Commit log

2025-09-20 Reorganize project structure: Move Yocto to Embedded/ directory
    - Move all Yocto/embedded components to Embedded/ subdirectory
    - Update .gitignore to reflect new structure and support future web development
    - Create comprehensive README.md explaining project structure
    - Preserve Git history by using git mv for all file movements
    - Prepare structure for future web development components
    [getopts.cfg, init.cfg, login-utilities.cfg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]
2025-09-20 feat: add meta-raspberrypi as submodule on scarthgap branch
    - Added meta-raspberrypi submodule for Raspberry Pi BSP support
    - Updated .gitignore to allow meta-raspberrypi
    - Configured submodule to track scarthgap branch for Yocto 5.0 compatibility
2025-09-20 feat: add rpi4 build configuration and files
    - Added complete rpi4 build environment
    - Includes bblayers.conf and local.conf for Raspberry Pi 4
    - Added build logs and configuration for embedded car image
    - Ready for Raspberry Pi 4 development
    [templateconf.cfg]
2025-09-21 Automatic Wifi Connection implemented - Added personalized recipe - Added basic gpio console control - Added gitignore folders
    [wifi.cfg]
2025-10-01 3d Models
    [Direction.stl, chassis.stl, motorBracketSmall.stl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]
2025-10-02 Added login and button controller
2025-10-02 Button controller update
2025-10-05 Connection with backend and camera integration
2025-10-06 Improved FPS Camera Streaming
2025-10-06 Added functionality to the camera and arrow keys section of the keyboard.
2025-10-06 Gradual movement by gears
2025-10-07 PWM for DC Motor Control Implemented * Note: PWM is still not working on servo motor
    [gpio_controller.c, gpio_lib.h]
2025-10-07 Software PWM chekcpoint + implemented configurable ip in gpio_controller
    [pwm.cfg]
2025-10-07 commented on prints to increase performance
2025-10-09 Edit README.md Correction on used drivers
